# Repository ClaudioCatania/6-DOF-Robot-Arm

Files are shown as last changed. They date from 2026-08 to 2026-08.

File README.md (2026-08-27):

# 6-DOF Robot Arm

A six axis robot arm built around 3D printed cycloidal reducers on NEMA 17 steppers.
Designed in Fusion 360, printed on a Bambu Lab A1.

I study mechanical engineering at Sapienza and this is my own project, outside of coursework.
What I want out of it is a modular arm, meaning every joint is the same kind of assembly:
one stepper, one cycloidal stage, one output flange. Scaling a joint should then be a matter
of changing dimensions, not of redesigning it.

Prototypes that got dropped are kept here together with the reason they were dropped. So far
I have learned more from those than from the ones that worked.

## Status

| | State |
|---|---|
| Cycloidal drive V1 | Printed, assembled, tested. It turns, but it is heavier than it needs to be and the printed ring pins rub. |
| Cycloidal drive V2 | In CAD. The ring pins become M3 screws with a bearing on top, which should turn the sliding contact into a rolling one. |
| J1, base joint | Prototype 1 built with a belt stage, then dropped. See [design log 0001](docs/design-log/0001-j1-belt-driven-base.md). |
| J2 to J6 | Not started. |

## How a joint is built

The same recipe everywhere:

- NEMA 17 stepper, 42 x 42 x 40 mm
- single stage cycloidal reducer, with the ring gear cut directly into the joint housing so
  it is not a separate part
- deep groove ball bearing on the output, 6812 (60 x 78 x 10) on the large joints
- Ø8 shafting and a Ø60 output flange as the interface between one joint and the next
- PLA on a Bambu Lab A1, 20% gyroid infill, speed reduced from the standard profile for
  dimensional accuracy

The parts that take real load are off the shelf: bearings, M3 screws, threaded inserts. The
printed parts mostly hold those in the right place.

## Why cycloidal

I looked at planetary reducers, harmonic drives and off the shelf smart servos first.
Harmonic drives are out of budget. Smart servos would work, but they hide the part of the
problem I actually wanted to work on. A cycloidal stage gives 20:1 or more in a single stage,
takes shock loads better than a printed planetary, and I can print it.

The price is that it is sensitive to print accuracy. Getting V1 to turn smoothly took several
calibration prints for hole and contour compensation before any real part came out usable.

## Repository layout

```
docs/design-log/     one entry per design decision, rejected ones included
cycloidal-drive/     the reducer module, shared by every joint
J1/                  base joint, yaw
```

Each module folder has its own README and a `cad/` folder with STEP files. Anything under
`cad/rejected/` was built or fully modelled and then abandoned.

## Design log

| # | Entry | Joint | Status |
|---|---|---|---|
| [0001](docs/design-log/0001-j1-belt-driven-base.md) | Belt driven J1 base, prototype 1 | J1 | Rejected |

## Licence

CERN-OHL-S v2, see [LICENSE](LICENSE). It is a hardware licence and it is strongly
reciprocal: you can use and modify these designs, but modified versions have to be released
under the same terms.

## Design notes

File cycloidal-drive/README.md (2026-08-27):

# Cycloidal drive

The reducer used at every joint of the arm. V1 is built and running, V2 is in CAD.

## V1 specifications

| Parameter | Value |
|---|---|
| Eccentricity | 1.37 mm |
| Reduction ratio | 1:20 |
| Ring gear pins | 21, 3D printed, integrated into the housing |
| Cycloidal disc thickness | 7 mm |
| Output pin holes | Ø8 mm |

## Bearings

| Quantity | Size | Function |
|---|---|---|
| 2 | 20x32x7 | Shaft to disc |
| 1 | 20x32x7 | Output to rear of the drive |
| 12 | 3x8x4 | Output pins |
| 1 | 60x78x10 | Output to ring gear |

## Fasteners

| Quantity | Item |
|---|---|
| 8 | M3 screws, 35 mm |
| 8 | M3 nuts |
| 6 | M3 screws, 25 mm |
| 12 | M3 threaded inserts |

## Print settings, Bambu Lab A1

- Infill: 20% gyroid. Good compromise between stiffness, weight and taking load from more
  than one direction.
- Speed: reduced from the standard profile, for dimensional accuracy.
- Material: PLA.

Hole and contour compensation on the XY plane were calibrated with test prints before any
real part was printed. Without that step the bearing seats came out too tight to use.

## Design problems I ran into

- **Sizing the main bearing.** The 60x78x10 had to have a bore larger than the circle the
  output pins sit on, otherwise it would run into them.
- **The smaller bearings.** The 20x32x7 and the 3x8x4 were picked after several iterations,
  to fit the disc dimensions I had settled on.
- **Interference fits.** Getting these to hold without splitting the part took several
  prototypes.

## V1 status

- [x] Geometry defined, eccentricity and ratio
- [x] Bearings sized
- [x] Print settings calibrated
- [x] Hole and contour compensation calibrated on test prints
- [x] Parts printed
- [x] Assembled and tested

It turns and it works. Three things are wrong with it:

1. It is heavier than it needs to be.
2. The two discs touch each other slightly.
3. The ring gear pins are printed and rub. This is the real problem: the disc slides against
   the pin instead of rolling on it, and no amount of lubricant fixes a sliding contact.

## V2, in CAD

The main change is the ring pins. Instead of printed posts, each pin becomes an M3 screw
passing right through the housing, with a heat set insert, a 3x8x4 bearing and a printed
spacer on it. The bearing outer race becomes the pin, so the contact turns from sliding to
rolling, and the screw is supported at both ends instead of cantilevered.

The spacers have to touch only the inner race of the bearing, so their outside diameter has to
stay at 5 mm or less. Standard M3 washers are 7 mm across and would press on the outer race
and lock the bearing.

I also changed the number of the theets of the ring gear from 21 to 24 so the reduction ratio in 1:23 and the ring gear can be sealed to the bearing housing with an even number of bolts

Still to do on V2: fillets of 1 to 2 mm on the inside corners of the lightening windows, and
screws with a plain unthreaded shank in the bearing area rather than thread all the way.

## Files

| Path | What it is |
|---|---|
| `cad/CycloidalDriveV1Assembly.f3z` | V1 assembly, Fusion 360 archive |

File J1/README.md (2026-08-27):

# J1, base joint

J1 is the base. It rotates about a vertical axis and carries the whole arm above it.

Because the axis is vertical, gravity produces no torque about J1. The motor only has to
beat inertia and friction. What the base does have to survive is the overturning moment of
the arm hanging out to one side, but that is a load on the output bearing and on the housing,
not on the motor. Mixing up those two is how prototype 1 ended up geared at 80:1, which is
about ten times what the joint needs.

## Current state

Prototype 1 is built and rejected. A GT2 belt stage at 4:1 sat upstream of a 20:1 cycloidal
stage, with the motor beside the axis instead of under it. The full reasoning is in
[design log 0001](../docs/design-log/0001-j1-belt-driven-base.md).

What survives from it: the housing doubling as the cycloidal ring gear, the 6812 output
bearing, the Ø115 housing and the Ø60 output flange.

The coaxial revision is not designed yet, and the ratio for it is still open. See the open
questions at the end of entry 0001.

## Files

| Path | What it is |
|---|---|
| [`cad/rejected/j1-belt-base-v1/PrototipoBase1.step`](cad/rejected/j1-belt-base-v1/PrototipoBase1.step) | prototype 1, as built |

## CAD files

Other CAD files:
J1/cad/rejected/j1-belt-base-v1/PrototipoBase1.step
cycloidal-drive/cad/CycloidalDriveV1Assembly.f3z

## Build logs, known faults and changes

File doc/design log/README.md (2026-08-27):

# Design log

One entry per design decision, numbered in the order it was taken. Rejected designs get an
entry as well, since the reason something was dropped is usually the useful part.

| # | Entry | Joint | Status |
|---|---|---|---|
| [0001](0001-j1-belt-driven-base.md) | Belt driven J1 base, prototype 1 | J1 | Rejected |

## Writing an entry

Follow the shape of entry 0001:

1. What was built or proposed, with the numbers taken from CAD in a table.
2. Why the decision went the way it did, one short section per reason, each with its own
   arithmetic.
3. What changes as a result.
4. What is worth keeping from the design that was dropped.
5. What is still open.

Say which numbers are measured and which are assumed. Most of the numbers here are still
assumed, and that is worth being upfront about.

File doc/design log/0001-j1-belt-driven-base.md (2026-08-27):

# 0001 — Belt driven J1 base, prototype 1

**Status:** rejected
**Date:** 2026-08-26
**Joint:** J1, base yaw
**CAD:** [`J1/cad/rejected/j1-belt-base-v1/PrototipoBase1.step`](../../J1/cad/rejected/j1-belt-base-v1/PrototipoBase1.step)

## Summary

The first base prototype drove J1 with a GT2 belt stage (20T to 80T, 4:1) upstream of a
21 pin cycloidal stage (20:1), so 80:1 overall. The motor sat 81.93 mm to the side of the
axis so that its 40 mm body did not stack under the reducer.

I dropped it because the belt can lose position with nothing watching, because its tension
permanently loads the one shaft that carries the cycloidal eccentric, and because the height
it saves costs more in footprint than it is worth. 80:1 also turned out to be far more
reduction than J1 needs.

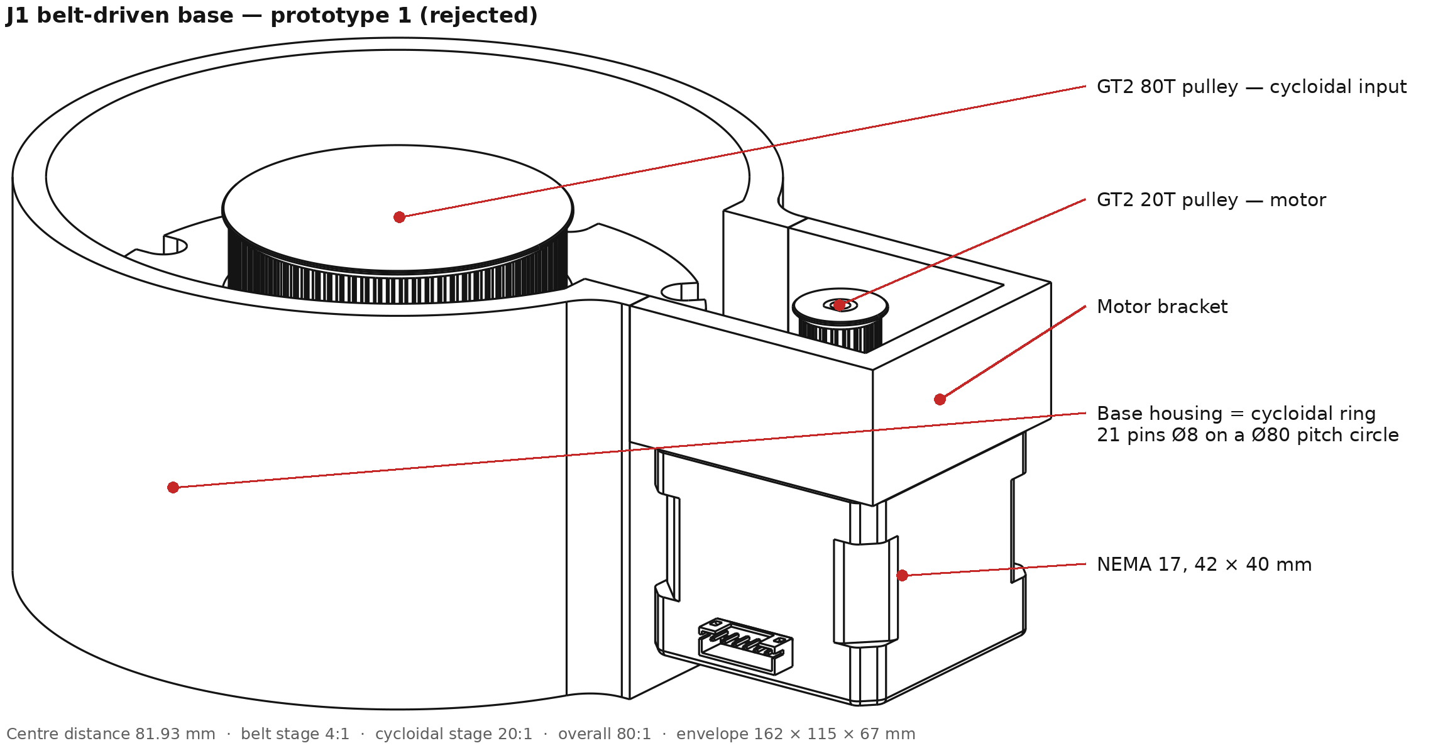
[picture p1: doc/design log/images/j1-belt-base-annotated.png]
Annotated view of the rejected prototype


## What was built

Measured from the CAD assembly:

| Item | Value |
|---|---|
| Motor | NEMA 17, 42 x 42 x 40 mm |
| Belt stage | GT2, 20T to 80T, 11 mm tooth face |
| Pitch diameters | 12.73 mm / 50.93 mm |
| Centre distance | 81.93 mm, fixed, no tensioner modelled |
| Belt length needed | 268.3 mm, 134 teeth |
| Cycloidal stage | 21 ring pins Ø8 on a Ø80 pitch circle, 20 lobe disc, 20:1 |
| Main bearing | 6812, 60 x 78 x 10 mm |
| Output | Ø60 flange, 8 mm shaft interface |
| Overall ratio | 4 x 20 = 80:1 |
| Envelope | 161.9 x 115.0 x 67.0 mm, motor included |

The motor hangs shaft down at X = -81.93 mm with its 20T pulley at the bottom of the base.
The 80T pulley sits on the cycloidal input shaft, on the J1 axis. The cycloidal ring is cut
into the base housing itself and the 6812 carries the output flange at the top.

Power path, rejected vs coaxial

## Why it was rejected

**The belt can lose position and nothing would see it.** Pulley clearance itself is not the
issue: it sits upstream of the reducer, so 0.05 to 0.1 mm of belt travel is only 0.02 to
0.05° at the output. The issue is that both pulleys are printed, and a printed 80T GT2 pulley
has real pitch error and runout that repeats once per input revolution and goes straight
through the cycloidal stage. It also drifts, since tension falls as the printed bracket creeps
and moves with temperature. And with the step count taken at the motor, everything downstream
is open loop, so a skipped tooth is a permanent 0.9° error at J1 that never comes back.

**Belt tension loads the shaft that must not deflect.** A NEMA 17 at 0.40 N·m with a 20T
pulley (pitch radius 6.37 mm) gives about 63 N of tangential force. Belts are tensioned at
roughly 1.0 to 1.5 times that and the two spans add on the shaft, so both pulley shafts carry
95 to 125 N of standing radial load whether the joint moves or not. On the driven side that
shaft carries the cycloidal eccentric, and the mesh is defined by the eccentricity, so any
deflection there adds to it directly and changes which lobes touch. The steel shaft barely
moves, about 0.01 mm for Ø8 over a 20 mm overhang, but it sits in printed bearing seats and
PLA creeps under a load that never goes away. That is the worst load case for printed plastic,
and here it exists only to keep a belt tight.

**The height saving costs more than it saves.**

| | Belt version, built | Coaxial NEMA 17, estimate |
|---|---|---|
| Height, base plate to output face | 67 mm | about 88 mm |
| Footprint | 162 x 115 mm | Ø115 mm |
| Extra parts | 2 pulleys, belt, input shaft, 2 bearings | none |

The belt buys about 21 mm, and it buys it below the J1 flange, which is pedestal height and
can be recessed into whatever the arm is bolted to. What it adds is 47 mm sideways, at the
level where J1's own link sweeps. Trading a round base for a lopsided one to save pedestal
height is the wrong way round. There is also no tensioner in the model: the centre distance is
fixed, which pins the belt at 268.3 mm, not a stock closed loop length in most GT2 ranges, and
leaves no way to re-tension it once the printed parts creep.

**It breaks the modularity rule.** Every other joint is meant to be a cycloidal drive on a
NEMA 17. A belt gives J1 its own power path, bracket, failure mode and spare part.

## The ratio was wrong too

J1 turns about a vertical axis, so gravity produces no torque about it and the ratio is not
set by a holding load. It is bounded below by the torque needed to accelerate the arm and
above by the output speed the motor can still deliver.

These are estimates, not measurements. Links 1 to 3 do not exist yet, so the load inertia is a
guess for a 2.0 kg arm with a 0.5 kg payload at 0.40 m. Usable motor torque 0.24 N·m (0.6 of
0.40 N·m holding), assumed stage efficiency 0.75, target 90 °/s reached in 0.30 s, useful
motor speed 600 rpm at 24 V.

```
T_acc = 0.125 kg·m² x 5.24 rad/s²   = 0.65 N·m
T_req = 0.65 + 0.50 friction        = 1.15 N·m
i_min = 1.15 / (0.24 x 0.75)        = 6.4
i_max = 600 rpm / 15 rpm            = 40
```

Anything between roughly 6.4 and 40 works. The 20:1 stage alone gives 3.60 N·m against
1.15 N·m needed, a safety factor of 3.1, and 180 °/s. The belt pushes it to 80:1, which is
14.4 N·m and 45 °/s. Nothing on this arm needs 14 N·m about a vertical axis, and halving the
slew speed to get it is a bad trade.

Where 80:1 does win is inertia matching. At 20:1 the reflected load inertia is about 58 times
the rotor, which is high, and the stepper will feel it during hard ramps. I am accepting that
on purpose: it can be handled with S curve ramps, by keeping the arm light, and by closing the
loop on J1 later if it turns out to matter. It is a tuning problem, and a belt is a mechanical
one.

## Decision

- Drop the belt stage, mount the NEMA 17 coaxially under the cycloidal drive.
- Keep the 6812 output bearing, the Ø60 output flange, the Ø115 housing and the
  housing-as-ring-gear idea. Those parts of prototype 1 were right.
- Ratio of the coaxial version not decided yet, see below.

## Open question: how many ring pins

A single disc cycloidal drive with N ring pins and an N-1 lobe disc gives a ratio of N-1, so
the ratio is chosen by picking the pin count, and the pin count is limited by how much
material is left between pins.

| Pins on Ø80 | Ratio | Pin spacing | Web between Ø8 pins |
|---|---|---|---|
| 21, built | 20:1 | 11.97 mm | 3.97 mm |
| 24 | 23:1 | 10.47 mm | 2.47 mm, too thin |

24 pins would only fit with the pins at Ø6 instead of Ø8. That looks free on the drawing but
it is not, because from V2 the pin is no longer printed: it is an M3 screw with a 3x8x4
bearing on it, and the outer race of that bearing is the pin. Ø6 means a 3x6x2.5 bearing, so
contact width drops from 4 mm to 2.5 mm and every pin carries less. Adding three pins while
weakening all of them, to gain 15% of a ratio that already has a safety factor of 3.1, is not
obviously worth it. Leaning towards 21 pins and 20:1, which also reuses the discs and the
3x8x4 bearings I already have. Not decided.

## Other open points

- [ ] Check the load inertia on the real arm once links 1 to 3 exist. The ratio rests on it.
- [ ] Measure the real efficiency of the printed cycloidal stage. 0.75 is a guess.
- [ ] Decide whether J1 gets an output side encoder before committing to open loop.

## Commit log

2026-08-20 Create README.md for Cycloidal Drive, first version
    I just finished designing the first version of the cycloidal drive that I will use for J2, here’s the readme with all the specifications and problems i came across
2026-08-22 Added the Fusion360 Assembly File of J1/J2 cycloidaldriveV1
    [CycloidalDriveV1Assembly.f3z]
2026-08-27 Rename 0001-j1-belt-driven-base.md to doc/design log/0001-j1-belt-driven-base.md
2026-08-27 Rename j1-belt-base-annotated.png to doc/design log/images/j1-belt-base-annotated.png
